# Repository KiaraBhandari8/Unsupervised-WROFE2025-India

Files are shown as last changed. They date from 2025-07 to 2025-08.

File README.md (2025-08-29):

# Unsupervised-WROFE2025-India
This is a repository for our WRO Future Engineers 2025 documentation. 

## Table of Contents
- [Unsupervised-WROFE2025-India](#unsupervised-wrofe2025-india)
  - [Table of Contents](#table-of-contents)
  - [Team](#team)
  - [About the challenge](#about-the-challenge)
  - [List of Components](#list-of-components)
  - [Robot Pictures](#robot-pictures)
  - [Design, Build, Code and Evaluate Process](#design-build-code-and-evaluate-process)
    - [Design](#design)
    - [Mobility Management](#mobility-management)
      - [Powertrain](#powertrain)
        - [Drivetrain](#drivetrain)
        - [Motor](#motor)
        - [Motor Driver](#motor-driver)
    - [Build](#build)
      - [Chassis](#chassis)
      - [Steering Mechanism](#steering-mechanism)
      - [Drive Mechanism](#drive-mechanism)
    - [Sensors and Perception](#sensors-and-perception)
      - [LiDAR – YDLIDAR T-mini Plus](#lidar--ydlidar-t-mini-plus)
      - [Camera – Raspberry Pi Camera Module 3 (Wide)](#camera--raspberry-pi-camera-module-3-wide)
    - [Power and sense management](#power-and-sense-management)
        - [DC Buck Converter:](#dc-buck-converter)
      - [Lithium Ion batteries:](#lithium-ion-batteries)
      - [Open Round Algorithm](#open-round-algorithm)
      - [Obstacle Round Algorithm](#obstacle-round-algorithm)
    - [Final Evaluation \& Scores](#final-evaluation--scores)
- [🚀 Robot Construction Guide](#-robot-construction-guide)
  - [🖨️ Step 0: Print the 3D Parts](#️-step-0-print-the-3d-parts)
    - [1. Prepare the microSD Card](#1-prepare-the-microsd-card)
    - [2. First Boot](#2-first-boot)
    - [3. Enable Required Interfaces](#3-enable-required-interfaces)
  - [Running the Code](#running-the-code)

## Team

<table style="width:100%; border: 1px solid black; border-collapse: collapse;">
  <thead>
    <tr>
      <th style="border: 1px solid black; padding: 8px;">Name</th>
      <th style="border: 1px solid black; padding: 8px;">Profile</th>
      <th style="border: 1px solid black; padding: 8px;">Role</th>
      <th style="border: 1px solid black; padding: 8px;">Contribution</th>
    </tr>
  </thead>
  <tbody>
    <tr>
      <td style="border: 1px solid black; padding: 8px;">1. Arnav Ramtake</td>
      <td style="border: 1px solid black; padding: 8px;">3rd year undergrad @ IIT Bombay</td>
      <td style="border: 1px solid black; padding: 8px;">Team Member</td>
      <td style="border: 1px solid black; padding: 8px;">Project development & Testing</td>
    </tr>
    <tr>
      <td style="border: 1px solid black; padding: 8px;">2. Kiara Bhandari</td>
      <td style="border: 1px solid black; padding: 8px;">Grade 9 @ Oberoi International School</td>
      <td style="border: 1px solid black; padding: 8px;">Team Member</td>
      <td style="border: 1px solid black; padding: 8px;">Project development & Testing</td>
    </tr>
    <tr>
      <td style="border: 1px solid black; padding: 8px;">3. Shubh Gupta</td>
      <td style="border: 1px solid black; padding: 8px;">Grade 9 @ Chatrabhuj Narsee School</td>
      <td style="border: 1px solid black; padding: 8px;">Team Member</td>
      <td style="border: 1px solid black; padding: 8px;">Project development & Testing</td>
    </tr>
    <tr>
      <td style="border: 1px solid black; padding: 8px;">4. Vinay Ummadi</td>
      <td style="border: 1px solid black; padding: 8px;">Mentor @ MakerWorks Lab</td>
      <td style="border: 1px solid black; padding: 8px;">Team Mentor</td>
      <td style="border: 1px solid black; padding: 8px;">Provided guidance and support</td>
    </tr>
  </tbody>
</table>

Team picture:

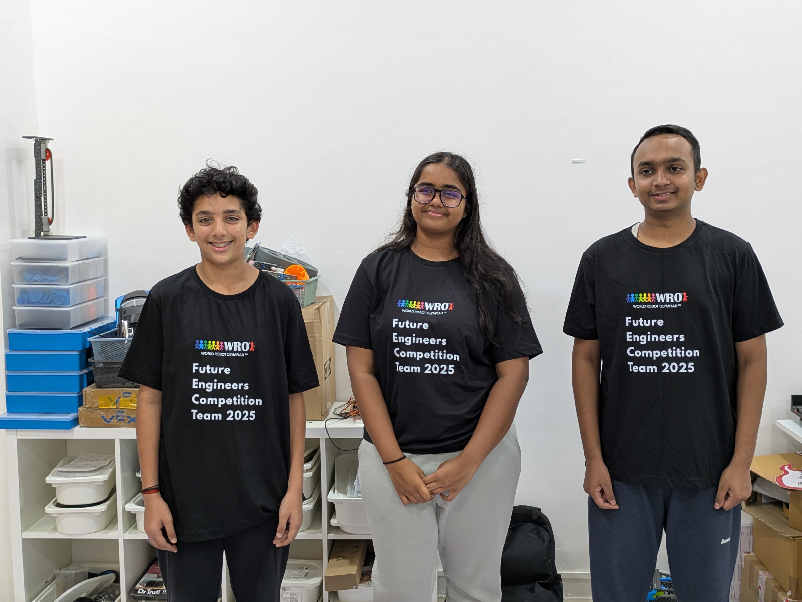
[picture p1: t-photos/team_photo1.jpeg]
Team Picture


## About the challenge
The World Robot Olympiad (WRO) is an international robotics competition that encourages students to develop problem-solving, programming, and engineering skills.
The Future Engineers category is designed for students aged 14–22 years and focuses on autonomous driving. The challenge simulates real-world traffic conditions and requires teams to design and program a fully autonomous robot car.

The challenge requires students to construct an autonomous robot which will undergo 2 rounds. First, an open round challenge where the robot would need to complete 3 rounds around the arena within the time limit of 3 minutes (180 seconds). The second round, which is the obstacle round consists of navigating through red and green pillars, where the robot would move from the left of the green pillar and from right of the red pillar. The robot should once again, not exceed a time limit of 3 minutes.

## List of Components
<table border="1">
  <thead>
    <tr>
      <th>Component Name with Link</th>
      <th>Quantity</th>
      <th>Price</th>
    </tr>
  </thead>
  <tbody>
    <tr>
    <td><a href="https://robu.in/product/n20-6v-600-rpm-micro-metal-gear-motor/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">N20 DC Gear Motor</a></td>
      <td>1</td>
      <td>₹239</td>
    </tr>
    <tr>
    <td><a href="https://robu.in/product/raspberry-pi-5-model-8gb/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">Raspberry Pi 5 (Cooling Fan + SD Card)</a></td>
      <td>1</td>
      <td>₹8,291</td>
    </tr>
      <tr>
    <td><a href="https://robu.in/product/raspberry-pi-camera-module-3-wide/"> Pi Camera 3 Wide Angle</a></td>
      <td>1</td>
      <td>₹500</td>
    </tr>
      <tr>
    <td><a href="https://share.google/GQIqzE7hObWl2JtNW">TB6612FNG Motor Driver</a></td>
      <td>1</td>
      <td>₹161</td>
    </tr>
      <tr>
    <td><a href="https://share.google/SYj7opQ4mhcO487lK">MG996R Servo Motor</a></td>
      <td>1</td>
      <td>₹347</td>
    </tr>
      <tr>
    <td><a href="https://robu.in/product/16-channel-12-bit-pwmservo-driver-i2c-interface-pca9685-arduino-raspberry-pi/">PCA9685 Servo Driver</a></td>
      <td>1</td>
      <td>₹223</td>
    </tr>
      <tr>
    <td><a href="https://share.google/BG01lgffrP5yxi8mK">N20 Wheels</a></td>
      <td>4</td>
      <td>₹140</td>
    </tr>
      <tr>
    <td><a href="https://share.google/xb8SxxgjGmudeReLK">LM2596S Voltage Regulator</a></td>
      <td>1</td>
      <td>₹41</td>
    </tr>
      <tr>
    <td><a href="https://robu.in/product/ydlidar-t-mini-plus-lidar-sensor/">YD LiDAR T-mini plus</a></td>
      <td>1</td>
      <td>₹9,595</td>
    </tr>
      <tr>
    <td><a href="https://www.amazon.in/Ambrane-Charging-Powerbank-Emergency-30/dp/B0D351GHY7?th=1">Power Bank</a></td>
      <td>1</td>
      <td>₹1,699</td>
    </tr>
      <tr>
    <td><a href="https://makerbazar.in/products/18650-3-7v-lithium-ion-rechargeable-cell-good-quality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">18650 Battery</a></td>
      <td>2</td>
      <td>₹35</td>
    </tr>
      <tr>
    <td><a href="https://share.google/fq9tZREMioah3AI9Q">Push Button Switch</a></td>
      <td>1</td>
      <td>₹46</td>
    </tr>
      <tr>
    <td><a href="https://robu.in/product/pct-spl-62-0-08-2-5mm-62-pole-wire-connector-terminal-block-with-spring-lock-lever-for-cable-connection/">Wire Connectors</a></td>
      <td>1</td>
      <td>₹58</td>
    </tr>
      </tr>
      <tr>
    <td><a href="https://www.mathaelectronics.com/product/4-pole-2-way-dpdt-12pin-on-off-switch/">4 Pole 2 Way DPDT 12 pin ON/OFF Switch</a></td>
      <td>1</td>
      <td>₹500</td>
    </tr>
    <tr>
    <td><a href="[https://share.google/fq9tZREMioah3AI9Q](https://www.amazon.in/dp/B0D9VWCX66?ref=ppx_yo2ov_dt_b_fed_asin_title)">RC Car Rear Differential</a></td>
      <td>1</td>
      <td>₹1,275</td>
    </tr>

  </tbody>
</table>

## Robot Pictures
<table border="1">
  <thead>
    <tr>
      <th>Top</th>
      <th>Bottom</th>
    </tr>
  </thead>
  <tr>
    <td>
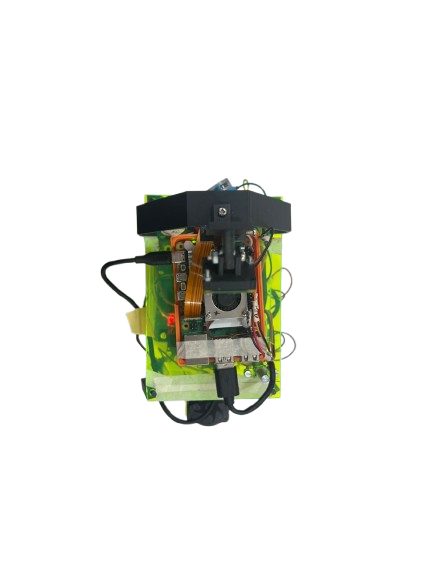
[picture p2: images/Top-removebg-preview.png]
Robot_Top
  </td>
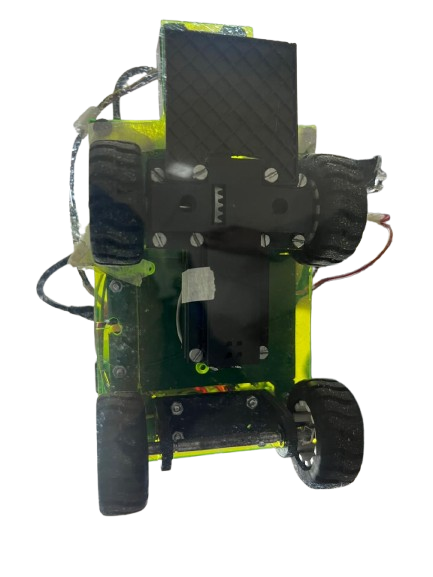
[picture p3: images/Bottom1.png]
Robot_Bottom
    <td></td>
  </tr>
  <thead>
    <tr>
      <th>Front</th>
      <th>Back</th>
    </tr>
  </thead>
  <tr>
    <td>
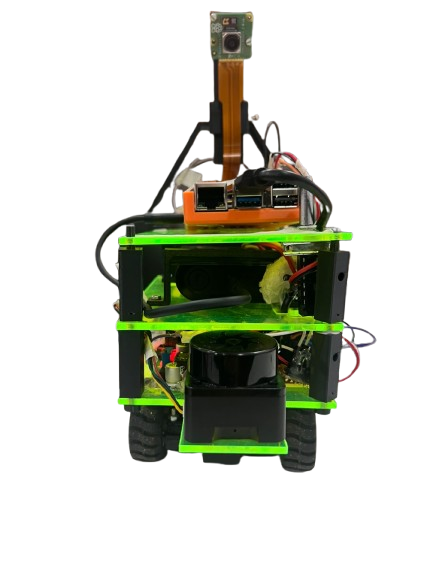
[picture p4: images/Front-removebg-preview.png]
Robot_Front
  </td>
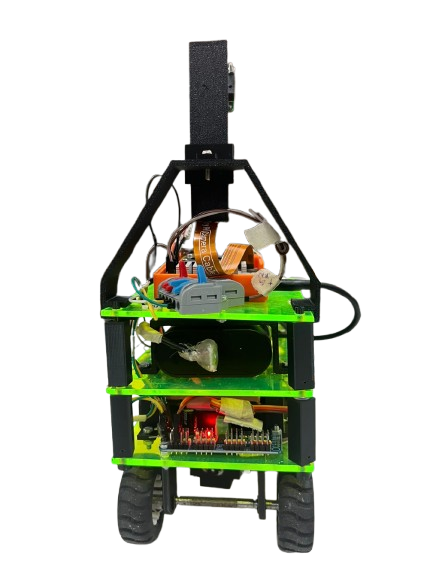
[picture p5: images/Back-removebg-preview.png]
Robot_Back
    <td></td>
  </tr>
   <thead>
    <tr>
      <th>Left</th>
      <th>Right</th>
    </tr>
  </thead>
  <tr>
    <td>
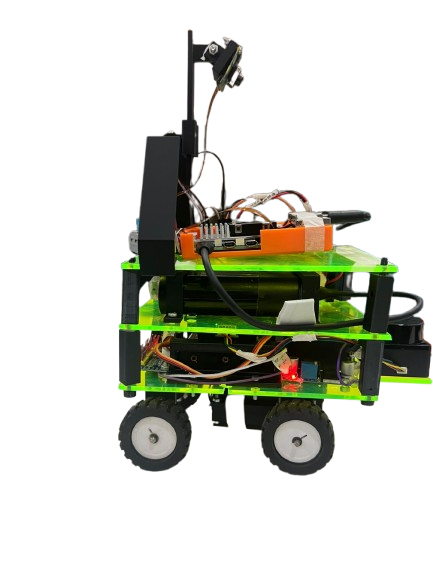
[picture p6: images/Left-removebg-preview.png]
Robot_Left
  </td>
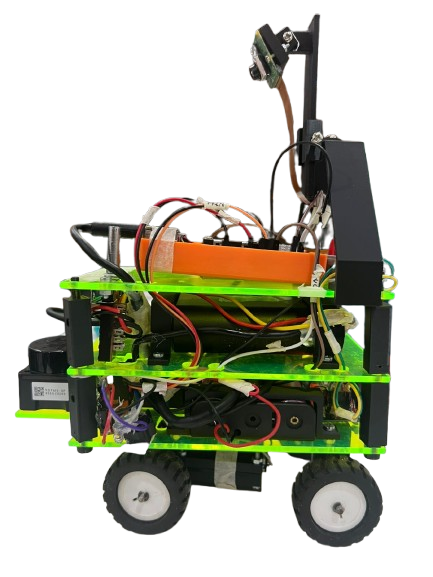
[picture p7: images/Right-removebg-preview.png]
Robot_Right
    <td></td>
  </tr>
</table>

### Design Process
We started understading the given constraints and physical requirements of the robot and then designed the robot to meet these requirements. The design process included:
- **Understanding the Problem Statement**: We analyzed the requirements and constraints of the WRO Future Engineers 2025 competition.
- **Conceptualizing the Robot**: We brainstormed ideas for the robot's design, focusing on its chassis, steering mechanism, drive mechanism, sensors, and power management.
- **Creating Design Diagrams**: We created detailed design diagrams to visualize the robot's structure and components. These diagrams included:
  - Chassis design
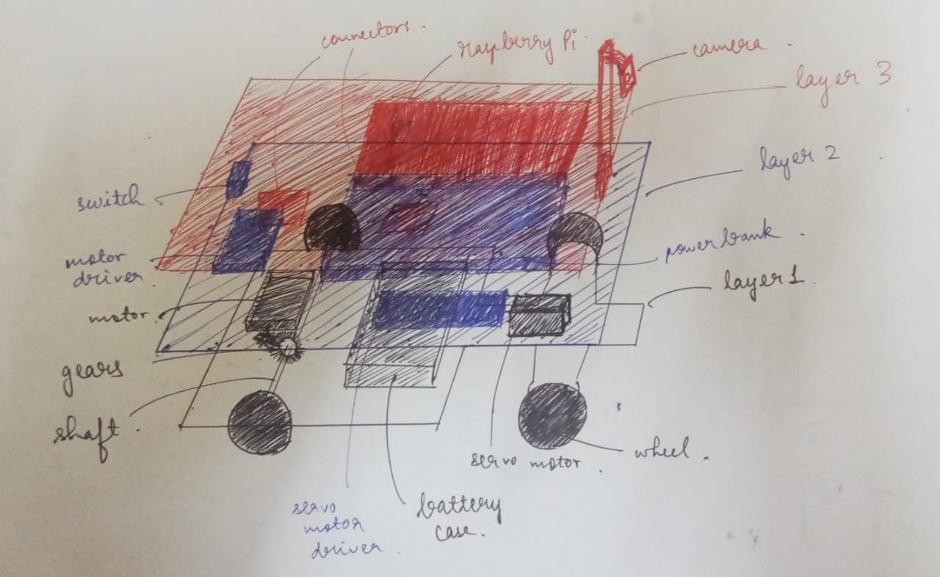
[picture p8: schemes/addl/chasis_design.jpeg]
Chasis Design Drawing
  

  - Steering mechanism design
  
  - Drive mechanism design      

### Mobility Management

The robot's mobility is managed by a combination of compoenents, icluding the powertrain, sterring system and chassis. These elements work together to ensure the robot's smooth and efficient movement. 

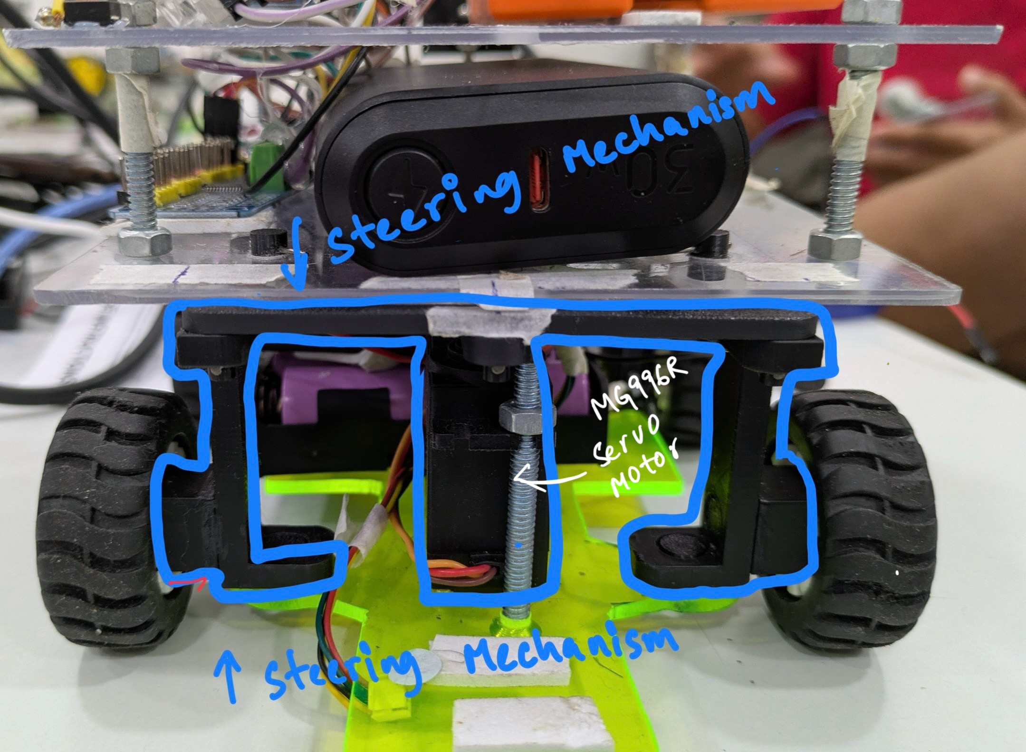
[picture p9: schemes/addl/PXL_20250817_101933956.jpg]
Drive Mechanism


#### Powertrain 

##### Drivetrain 
To minimize friction and therby reduce speed loss, driving axle was made from an steel rod. We connected the orot to the riving axle using a custom 3-D printed adapter. The driing axle is equipped with differential gears, which allow the robot to turn smoothly. For traction we used N20 wheels. 

Potential Improvements:

- Upgrade to higher-quality differential gear set for enhanced efficiency and smoother cornering. 
- Experiment with lighter alloys and hollow rods to balance strength with reduced weight. 
- Replace the 3D printed adapter with a kachined metal one for greater durability and precision. 

##### Motor

N20 DC Gear motor:
<table border="1">
  <thead>
    <tr>
      <th style="width:300;">Component Image</th>
      <th style="width:200;">Specifications:</th>
    </tr>
  </thead>
  <tbody>
      <tr>
        <td>N20 dc Gear motor</td>
        <td>
          1. Name: N20 dc Gear Motor
          <br>
          <br>
          2. Speed Range:  ~ 30 RPm to ~ 2000 RPM
          <br>
          <br>
          3. High torque at low RPM due to gearbox
        </td>
      </tr>
  </tbody>
</table>

Following an evaluation of different motors, we settles on the **N20-6V-600 Rpm Micro Metal Gear Motor**. THis motor was selected for its lightweight and compact design, which stands out among others with comparable output. We secured the motor to the chassis using a custom 3-D printed holder. 

Where to buy the motor: (insert link)

To connect the motor's axle to the chassis, we created a custom 3D - printed adapter. 

(insert 3D model)

Potential Improvements:
- Consider upgrading to a higher-torque or lower-RPM variant of the N20 motor for improved control and load handling.
- Replace the custom 3D-printed adapter with a machined metal connector to enhance strength and long-term reliability.
- Implement a sturdier motor mount or holder to minimize vibrations and ensure better alignment with the axle.

Drive Mechanism

##### Motor Driver 

To control the speed of the drive motor, we utilized the SparkFun Dual TB6612FNG motor driver. 

<table border="1">
  <thead>
    <tr>
      <th style="width:300;">Component Image</th>
      <th style="width:200;">Specifications:</th>
    </tr>
  </thead>
  <tbody>
      <tr>
        <td>TB6612FNG Motor driver</td>
        <td>
          1. Name: TB6612FNG
          <br>
          <br>
          2. Motor Voltage (VM): 4.5–13.5 V
          <br>
          <br>
          3. Logic Voltage (VCC): 2.7–5.5 V
          <br>
          <br>
          4. Output Current: 1.2 A continuous, 3.2 A peak per channel
          <br>
          <br>
          5. Control Pins: Direction, PWM speed, Standby
        </td>
      </tr>
  </tbody>
</table>

Where to buy the motor drive: https://www.sparkfun.com/sparkfun-motor-driver-dual-tb6612fng-with-headers.html

Potential Improvements:
- Replace the motor driver with a custom PCB to reduce weight and improve space utiliation 
- Add active cooling or heating sinks for enhanced thermal performance during extended use.
- Explore higher-current motor drivers to accomodate potential motor upgrades. 
- Implement a more robust power manangement system to ensure reliable operation. 

### Build

#### Chassis
The robot chasis is mainly designed from acrylic and 3d desgined parts. Robot consists of multiple layers to accommodate various components. Every structural component was fastened firmly with bolts and nuts to ensure durability and rigidity required for testing. For enhanced performance, the bottom acrylic sheet was carefully trimmed along the wheel areas, allowing for free wheel rotation and better maneuverability. Instead of expanding the robot's dimensyions in horizantally that would impact maneuverability, we opted for a three-layer vertical configuration. Not only did this choice in design improve space efficiency, but it also boosted the robot's performance by allowing better integration of its mechanical and electronic components in a compact footprint. The robot dimensions are 14cm(width) x 19cm(length) x 20cm(height). 

#### Steering Mechanism
The robot employs a distinct and novel steering mechanism designed to achieve efficient and reliable maneuvering using a single servo motor. An MG996R high-torque servo motor is directly coupled to the steering linkage, allowing both front wheels to turn at the same angle simultaneously. The forward wheels are free to rotate independently and are supported by a differential gear system, which ensures that each wheel can rotate at the appropriate speed when the robot takes a turn. This is essential because the outer wheel must travel a greater distance than the inner wheel during cornering, and the differential allows this motion without skidding or energy loss. By combining the servo-driven steering system with differential gears, the robot achieves precise steering control, mechanical efficiency, and smooth navigation across both straight paths and turns.
MG996r Servo Motor:
<table border="1">
  <thead>
    <tr>
      <th style="width:300;">Component Image</th>
      <th style="width:200;">Details</th>
    </tr>
  </thead>
  <tbody>
      <tr>
        <td>MG996r servo motor</td>
        <td>
          1. MG996r Servo motor
          <br>
          <br>
          2. Digital servo: Pulse width modulation controlled(PWM)
        </td>
      </tr>
  </tbody>
</table>

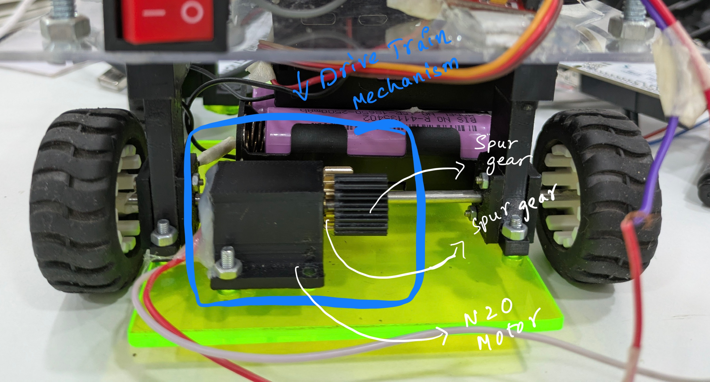
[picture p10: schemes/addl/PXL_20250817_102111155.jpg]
Steering Mechanism


#### Drive Mechanism
An N20 DC gear motor powers the driving mechanism of the robot,transferring motion to the rear axle of the wheels via a gear system.The N20 motor is a small and light device (around 12 mm in diameter and weighing 10–12 g), frequently utilized in miniature robotics and DIY projects. It comes in 3 V, 6 V, and 12 V options, featuring gear ratios from 10:1 to 1000:1, allowing for a balance of speed and torque—lower ratios yield increased speed, while higher ratios offer enhanced torque. Featuring a 3 mm D-shaped output shaft and a robust metal gearbox, the N20 motor provides easy mounting affordability, and versatility, making it ideal for applications like line-following robots,remote-controlled vehicles, and small actuation systems.

N20 DC Gear motor:
<table border="1">
  <thead>
    <tr>
      <th style="width:300;">Component Image</th>
      <th style="width:200;">Details</th>
    </tr>
  </thead>
  <tbody>
      <tr>
        <td>N20 dc Gear motor</td>
        <td>
          1. N20 dc Gear Motor
          <br>
          <br>
          2. Speed range (depends on gear ratio): from ~30 RPM (high torque) to ~1000 RPM (low torque)
          <br>
          <br>
          3. High torque at low RPM due to gearbox
        </td>
      </tr>
  </tbody>
</table>

Drive Mechanism

### Sensors and Perception

#### LiDAR – YDLIDAR T-mini Plus
<table border="1">
  <thead>
    <tr>
      <th style="width:300;">Component Image</th>
      <th style="width:200;">Details</th>
    </tr>
  </thead>
  <tbody>
      <tr>
        <td>YD Lidar T-mini plus
        <td>
          • Model: YDLIDAR T-mini Plus  
          <br><br>
          • 360° scanning capability for complete environmental awareness  
          <br><br>
          • Maximum range: up to 12 meters  
          <br><br>
          • Provides high-frequency distance and angle data for mapping and navigation
        </td>
      </tr>
  </tbody>
</table>

The LiDAR sensor operates on the principle of **time-of-flight measurement**, emitting rapid laser pulses and calculating the return time after striking objects. This provides precise range and angular data, enabling the robot to construct accurate real-time maps of its surroundings. Its wide scanning field, high accuracy, and fast update rate make it essential for **obstacle detection, Simultaneous Localization and Mapping (SLAM), and terrain mapping**. With LiDAR, the robot can not only avoid obstacles but also refine its spatial understanding continuously, ensuring smooth navigation even in dynamic or unfamiliar environments.

Potential Improvements:
+ Use RANSAC line fitting or clustering to detect walls and obstacles more reliably
+ Apply filtering (median, moving average, outlier rejection, low-pass on derivative) for smoother control inputs
+ Add gain scheduling or adaptive PID to adjust steering dynamically with speed and environment
+ Try predictive controllers like Pure Pursuit, Stanley, or MPC for smoother navigation
+ Fuse LiDAR with IMU/encoders for better localization and drift correction
+ Use dynamic window or VFH (Vector Field Histogram) for local obstacle avoidance
+ Apply SLAM or map-based localization for improved path planning in complex environments
+ Add trajectory prediction to handle moving obstacles effectively

#### Camera – Raspberry Pi Camera Module 3 (Wide)
<table border="1">
  <thead>
    <tr>
      <th style="width:300;">Component Image</th>
      <th style="width:200;">Details</th>
    </tr>
  </thead>
  <tbody>
<tr>
        <td>Raspberry Pi camera module 3 wide angle
        </td>
        <td>
          • 12 MP Sony IMX708 sensor with HDR support  
          <br><br>
          • 120° ultra-wide diagonal field of view (≈102° horizontal, 67° vertical)  
          <br><br>
          • Phase-detect autofocus for sharp imaging  
          <br><br>
          • 1080p video at up to 50 fps for real-time processing
        </td>
      </tr>
  </tbody>
</table>

The Raspberry Pi Camera Module 3 (Wide) was chosen due to its ability to capture a broad field of view, critical for detecting obstacles, monitoring lanes, and ensuring spatial awareness with fewer blind spots. Its **high-resolution sensor and HDR capability** deliver clear images across varying light conditions, while the autofocus ensures reliable detection of both nearby and distant objects. The **high frame rate (50 fps)** ensures smooth real-time video streaming, which is vital for **vision-based navigation, SLAM, and obstacle recognition**. This makes it an optimal perception sensor for the robot’s autonomous operation.

Potential Improvements:

+ Upgrade to a camera with higher resolution for better object detection and tracking.
+ Test alternative lighting solutions to improve visibility in various conditions.
+ Implement advanced image processing algorithms to enhance detection accuracy.
+ Use color correction algorithms: Apply color correction algorithms to compensate for any variations in lighting conditions. These algorithms can adjust the color values of the captured image to match a reference color space, making the colors more consistent and easier to calibrate.
+ Provide user-adjustable parameters: Allow users to manually adjust color thresholds or ranges to fine-tune the color detection. This can be done through a user interface or by providing configuration files that can be modified.
+ Implement real-time feedback: Display the detected colors in real-time to the user, along with the calibrated values. This allows users to visually verify the accuracy of the color detection and make adjustments if necessary.

### Power and sense management

##### DC Buck Converter:
<table border="1">
  <thead>
    <tr>
      <th style="width:300;">Component Image</th>
      <th style="width:200;">Details</th>
    </tr>
  </thead>
  <tbody>
      <tr>
        <td>LM2596S Voltage Regulator</td>
        <td>
          1. DC buck converter  
          <br>
          <br>
          2. A buck converter or step-down converter is a DC-to-DC converter which decreases voltage, while increasing current, from its input (supply) to its output (load)
          <br>
          <br>
          3. DC-DC converter
        </td>
      </tr>
  </tbody>
</table>

The robot is powered by a 3-cell 18650 battery pack (~11.1 V nominal), which acts as the main source of energy. Since the subsystems operate at different voltages, a two-rail power setup is used:

+ Direct 11.1 V rail – drives components that can operate directly from the pack
+ 3.3 V regulated rail – derived using an LM2596 buck DC-DC converter

The LM2596 was chosen because it provides 80–90% efficiency, avoiding the excessive heat losses of linear regulators. It also ensures:

+ Stable 3.3 V output across the pack’s 9–12.6 V range
+ Reliable operation of sensors, logic, and microcontrollers
+ Adequate current headroom for the control electronics
+ Simplified power management and protection of sensitive devices

#### Lithium Ion batteries:
 <table border="1">
  <thead>
    <tr>
      <th style="width:300;">Component Image</th>
      <th style="width:200;">Details</th>
    </tr>
  </thead>
  <tbody>
 <tr>
        <td>18650 lithium ion batteries
        </td>
        <td>
          1. 18650 Lithium Ion batteries (11.1 V) 
          <br>
          <br>
          2. High energy density and capacity, leading to longer usage times and more power in a small package. 
        </td>
      </tr>
  </tbody>
</table>

The robot is powered by a 3-cell 18650 non-rechargeable battery pack (11.1 V nominal), selected to balance reliability, compactness, and sufficient energy supply for autonomous operation.

+ Stable voltage output – consistently provides ~11.1 V (9–12.6 V range) suitable for motors, sensors, and control boards
+ Non-rechargeable chemistry – eliminates risks of recharge-related degradation, swelling, or maintenance, ensuring dependable short- to medium-term use
+ Motor compatibility – higher voltage level supports motor drivers more effectively than AA or 9 V alternatives
+ Extended runtime – high energy density of 18650 cells delivers longer operation before replacement compared to conventional disposable batteries
+ Compact and lightweight – cylindrical form factor makes the pack easy to integrate without adding unnecessary bulk
+ Consistent discharge curve – maintains steady performance over usage cycle, preventing voltage drops that could affect control electronics

### 18650 Battery holder
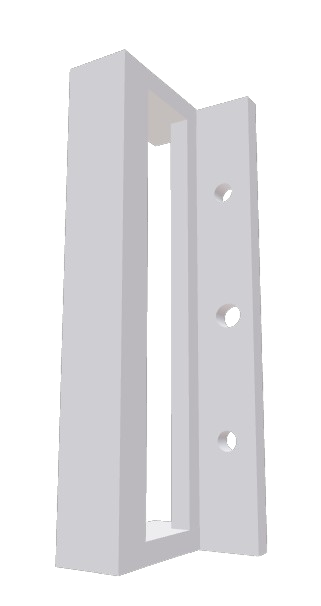
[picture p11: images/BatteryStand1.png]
Battery Holder


+ Compact Form Factor – The slim rectangular frame securely houses the 3-cell 18650 pack while minimizing wasted volume, making it well-suited for robots with limited internal space.
+ Structural Stability – The rigid walls and elongated side frame provide strong mechanical support, preventing cell movement or vibration during operation.
+ Mounting Flexibility – Pre-drilled holes allow easy attachment to the robot chassis, reducing the need for additional brackets or adhesives.
+ Weight Optimization – Open frame design reduces unnecessary material use, keeping the holder lightweight without compromising durability.
+ Thermal Management – The open sides promote airflow around the batteries, preventing heat buildup and improving safety during high-current discharge.
+ Maintenance-Friendly – The accessible frame allows straightforward battery replacement, inspection, or wiring adjustments.
+ Secure Alignment – Ensures the 18650 cells remain aligned in series/parallel configuration, reducing electrical contact resistance and improving power reliability.

#### Power Bank holder:
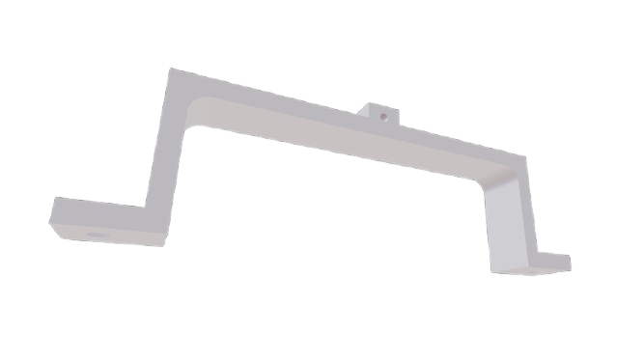
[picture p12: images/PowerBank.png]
Power Bank Holder


+ Minimalistic frame reduces material use, keeping it lightweight yet strong
+ Raised side arms secure the power bank and prevent shifting during operation
+ Central mounting hole allows easy attachment to the chassis
+ Open design ensures quick access for wiring and charging without removal
+ Provides airflow around the power bank for passive cooling
+ Stable and practical mounting without adding bulk to the robot

#### Potential Improvements:
+ Use rubber padding or cushioning to reduce shock and protect the power bank from mechanical stress.
+ Design for tool-less removal so the power bank can be swapped quickly.
+ Include cable management features (clips or slots) to keep wires tidy and strain-free
+ Add universal sizing adjustability to fit different power bank models if needed.
+ Optimize the weight distribution so the holder doesn’t affect the robots performance

## Open Round Algorithm
### 1) Initialization
+ Robot initializes LiDAR and motion subsystems.
+ A 5-second pause allows hardware to stabilize.
+ PID controller parameters (Kp, Ki, Kd) are set depending on clockwise/anticlockwise wall-following mode.

### 2) LiDAR Data Acquisition
+ The LidarScanner continuously collects angle–distance pairs (-180° to +180°).
+ Distances are filtered to valid ranges, converted to millimeters, and stored in a dictionary.

### 3) Turn Detection
+ Front LiDAR readings (±10° sector) are averaged separately for left and right.
+ If both fall within a threshold range (1500–2000 mm), the system flags a turn condition.
+ Turn events are counted, but with a cooldown (≥2.5 s) to avoid multiple detections for the same turn.

### 4) Wall Distance Processing
+ Right wall sector: 30° to 90°.
+ Left wall sector: -90° to -30°.
+ Front sector: -5° to +5° (safety check).
+ Distances in each sector are averaged to estimate proximity to arena walls.

### 5) Error Calculation:
The four conditions include:
+ If both walls are visible: error = (right distance – left distance) → keeps robot centered.
+ If only one wall is visible: error = (wall distance – target distance) → maintains fixed offset.
+ If no walls detected: error = 0 → hold course.
+ If front obstacle is closer than safety threshold (e.g., <300 mm): error = 9999 (forces emergency stop).

### 6) PID Control
+ The error is fed into a PID controller to smooth steering response.
+ PID output adjusts servo angle around a center position (≈95°).
+ Output is clamped to ±20° for safe steering limits.

### 7) Motion Control
+ If no obstacle: robot moves forward at constant speed (0.6).
+ Servo adjusts steering continuously to minimize PID error.
+ If obstacle detected: robot stops, pauses, and waits before continuing.

### 8) Termination Condition
+ After max_turn_count = 12 turns, the robot stops permanently (end of round).

## Step by step breakdown of functions (Open Round):

### 1) read_lidar_data(lidar):
``` bash
def read_lidar_data(lidar):
    """
    Reads distance values from the LiDAR sensor between -90° and +90°.
    Splits the scan into LEFT, RIGHT, and FORWARD zones.
    Returns the average distance in each zone to minimize noise.
    """
    scan = lidar.get_scan()   # assumes lidar API gives [(angle, distance), ...]

    # Split the scan into zones
    left_distances = [d for (a, d) in scan if -90 <= a < -30]
    right_distances = [d for (a, d) in scan if 30 <= a <= 90]
    forward_distances = [d for (a, d) in scan if -15 <= a <= 15]

    # Compute average values (if no points, default to 0)
    left_avg = sum(left_distances)/len(left_distances) if left_distances else 0
    right_avg = sum(right_distances)/len(right_distances) if right_distances else 0
    forward_avg = sum(forward_distances)/len(forward_distances) if forward_distances else 0
    
    return left_avg, right_avg, forward_avg

```
### Explanation:
+ The LiDAR constantly scans in a 180° range around the front of the robot.
+ Data is divided into zones:
  + Left zone: -90° to -30°
  + Right zone: +30° to +90°
  + Forward zone: -15° to +15°
+ By averaging readings, sudden spikes (noise) are reduced.
+ The robot then knows how far it is from left wall, right wall, and any object in front.

### compute_wall_error:
``` bash
def compute_wall_error(left, right):
    """
    Calculates the lateral error between left and right distances.
    Positive error → robot is closer to the RIGHT wall, so it must steer LEFT.
    Negative error → robot is closer to the LEFT wall, so it must steer RIGHT.
    """
    return left - right
```
### Explanation:
+ This function ensures the robot stays centered in the arena.
+ If left > right → robot is drifting towards the right wall → needs to turn left.
+ If right > left → robot is drifting towards the left wall → needs to turn right.
+ The error value is passed into the PID controller for smooth correction.

### pid_controller:
```bash
integral = 0
prev_error = 0

def pid_controller(error, Kp=1.2, Ki=0.01, Kd=0.5, dt=0.1):
    """
    PID controller that takes in an error value and outputs a steering correction angle.
    - Proportional (P): reacts immediately to the error.
    - Integral (I): fixes long-term drift or bias.
    - Derivative (D): anticipates changes and prevents overshoot.
    dt: time difference between control cycles.
    """
    global integral, prev_error
    
    integral += error * dt
    derivative = (error - prev_error) / dt
    output = (Kp * error) + (Ki * integral) + (Kd * derivative)
    
    prev_error = error
    return output
```
### Explanation:
+ This is the core control function.
+ Works just like an autopilot system.
+ P (Proportional) – responds strongly to the current error.
+ I (Integral) – accumulates small errors over time (helps correct drift).
+ D (Derivative) – predicts future error change to avoid oscillations.
+ Outputs a steering correction angle for the servo.

### adjust_steering(servo, angle):
```bash
def adjust_steering(servo, angle):
    """
    Adjusts the MG996R steering servo based on PID output.
    Clamps the steering angle to [-45°, +45°] to prevent mechanical strain.
    """
    max_angle = 45
    angle = max(min(angle, max_angle), -max_angle)  # clamp
    
    servo.write(angle)  # assumes servo driver library
```

### Explanation:
+ Converts PID output into servo rotation.
+ Prevents excessive turning (>45°) which could damage servo or robot frame.
+ Responsible for real-time navigation corrections.

### control_motors(driver, speed):
``` bash
def control_motors(driver, speed):
    """
    Controls the TB6612FNG motor driver.
    Sends equal PWM speed signals to left & right motors for forward motion.
    Speed range is 0–255.
    """
    driver.set_motor_speed(speed, speed)  # equal speed for both wheels
```

### Explanation:
+ Keeps robot moving forward with a constant speed.
+ Uses PWM signals to the TB6612FNG driver.
+ If needed, can be extended to allow different left/right speeds for sharper turns.

### check_termination(forward_distance, lap_count, max_laps):
```bash
def check_termination(forward_distance, lap_count, max_laps=3):
    """
    Checks if the run should terminate.
    Conditions:
    - If forward distance < threshold → obstacle or wall detected.
    - If lap_count >= max_laps → required laps completed.
    Returns True if termination condition is met.
    """
    if forward_distance < 20:  # cm threshold
        return True
    if lap_count >= max_laps:
        return True
    return False
```

### Explanation:
+ Ensures robot doesn’t run forever.
+ Two termination conditions:
  + Obstacle detected in front (arena end or unexpected block).
  + All laps completed (challenge success).
+ Returns True → robot stops.

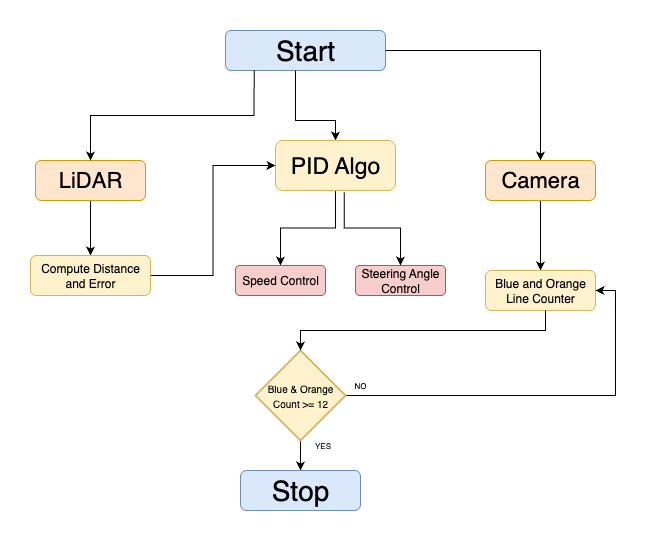
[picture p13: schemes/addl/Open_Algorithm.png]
Open Round Algorithm


## Obstacle Round Algorithm
The obstacle round uses a **hybrid sensing and control system** where LiDAR and camera inputs are fused together to identify obstacles, calculate errors, and generate steering corrections. The system is structured into multiple layers: sensing, perception, control, and actuation.

### 1) LiDAR-Based Obstacle Detection
+ **Sensor**: YDLidar T-mini Plus provides a **270° scan**, but only **-90° to +90° relative to robot’s forward axis** is considered.  
+ **Preprocessing**:  
  - Filters raw data for outliers (values beyond sensor max range).  
  - Segments detected points into clusters representing potential obstacles.  
+ **Pillar Identification**:  
  - Uses expected pillar spacing to detect red/green pillar positions.  
  - Calculates **lateral offset error** = difference between current robot position and target trajectory (pass left of green, right of red).  
+ **Use Case**:  
  - Provides **fail-safe navigation** when camera detection fails (e.g., poor lighting).  
  - Supplies continuous lateral distance measurement to support stable alignment.

### 2) Camera-Based Color Detection Algorithm
The camera system adds semantic information (pillar color), which LiDAR alone cannot provide.

+ **Frame Acquisition & Preprocessing**  
  - Captures frames using **PiCamera2** at 2304×1296.  
  - Resized and blurred to reduce noise before color segmentation.  
  - Conversion **BGR → HSV** for robust color thresholding under variable lighting.  

+ **Color Segmentation**  
  - Predefined HSV thresholds for **red** and **green**.  
  - Binary masks created for each color channel.  
  - Morphological operations (erode, dilate) applied to reduce noise.  

+ **Region of Interest (ROI)**  
  - Inner ROI = normal detection zone.  
  - Outer ROI = activated when LiDAR detects an obstacle cluster ahead.  
  - Dual-ROI design reduces false positives from irrelevant background features.  

+ **Contour Detection & Validation**  
  - Extracts contours from binary masks.  
  - Rejects contours smaller than **MIN_CONTOUR_AREA = 1500**.  
  - Selects the largest contour per frame as the obstacle candidate.  
  - Assigns detection labels:  
    - `"red_obstacle"` → valid red pillar.  
    - `"green_obstacle"` → valid green pillar.  
    - `"obstacle"` → unidentified object.  
    - `"none"` → no valid obstacle.  

+ **Depth Sensitivity Factor**  
  - Implements **DEPTH_IMPORTANCE_FACTOR = 1.35**.  
  - Vertical pixel location of contour centroid (closer to bottom = nearer).  
  - Error signal scaled accordingly:  
    - Far object → low correction.  
    - Near object → stronger correction.  

+ **Steering Logic (Camera)**  
  - Red pillar → steer left with correction `steering = KP_STEERING × error × depth_factor`.  
  - Green pillar → steer right with same correction logic.  
  - Maintains flexibility for real-time corrections based on object position.  

+ **Fallback Mechanisms**  
  - If **no obstacle detected** → black region between floor lines is used for centering.  
  - If **frame underexposed** → assumes corner → performs sharp left turn (≈ -45°).  
  - Prevents robot from stalling during sensor failure.  

+ **Debugging Visual Overlays**  
  - Draws bounding boxes, centroids, ROI zones, and target lines.  
  - Displays numerical feedback (depth factor, correction angle).  
  - Useful for tuning HSV thresholds and ROI positions in real-time.  

### 3) Sensor Fusion & PID Steering Control
+ **Error Calculation**  
  - `LiDAR_error` = difference between distances to left/right wall.  
  - `Camera_error` = lateral offset of detected pillar.  
  - Fusion weights:  
    - **LiDAR dominant** if no valid pillar detected.  
    - **Camera dominant** if pillar is confirmed in ROI.  

+ **PID Controller**  
  - Input = combined error (LiDAR + Camera).  
  - **Kp (Proportional)** → quick correction response.  
  - **Ki (Integral)** → compensates for slow drift across laps.  
  - **Kd (Derivative)** → damps oscillations during sharp turns.  
  - Tuning values are selected through iterative testing for balance between stability and responsiveness.  

+ **Output**  
  - PID output mapped to **MG996R servo angle**.  
  - Motor PWM adjusted to maintain forward speed while avoiding jerks during corrections.  

### 4) Decision Flow & Execution
+ Final control decision is based on **sensor fusion state**:  
  - `"red_obstacle"` → steer left of pillar.  
  - `"green_obstacle"` → steer right of pillar.  
  - `"corner_avoid"` → perform sharp predefined turn.  
  - `"line_centering"` → maintain lane using LiDAR + ROI fallback.  

+ **Actuation**  
  - Steering angle sent to **MG996R high-torque servo**.  
  - Motor commands executed via **TB6612FNG motor driver**.  
  - Smooth velocity profiles prevent skidding or abrupt turns.  

+ **System Reliability**  
  - Fusion of LiDAR (geometric accuracy) and Camera (semantic recognition) ensures **redundancy and robustness**.  
  - Fail-safes prevent deadlock when either sensor produces invalid data.  

## Step by step breakdown of functions (obstacle round):

### analyze_black_between_lines(frame, inner_start, inner_end):
```bash
def analyze_black_between_lines(frame, inner_start, inner_end):
    """
    Detects the amount of black pixels between two bounding lines (inner ROI).
    Balances left vs. right black regions to decide correction angle.
    """

    # Convert to grayscale
    gray = cv2.cvtColor(frame, cv2.COLOR_BGR2GRAY)
    x1, y1 = inner_start
    x2, y2 = inner_end

    # Extract Region of Interest (ROI)
    roi = gray[y1:y2, x1:x2]

    # Threshold black areas
    _, black_mask = cv2.threshold(roi, 60, 255, cv2.THRESH_BINARY_INV)

    # Split into left and right halves
    h, w = black_mask.shape
    left = black_mask[:, :w // 2]
    right = black_mask[:, w // 2:]

    # Count black pixels
    black_left = np.sum(left) / 255
    black_right = np.sum(right) / 255
    total_black = black_left + black_right

    # No black detected
    if total_black == 0:
        return None

    # Balance measure: positive → more black on right, negative → more on left
    balance = (black_right - black_left) / total_black

    # Apply gain factor
    correction = KP_LINE_CENTERING * balance * 100
    return correction
```

### Explanation:
+ Converts frame → grayscale and extracts a ROI between two guiding lines.
+ Thresholds dark areas (black tape or shadows).
+ Splits into left and right halves:
  + If more black is on the left → robot drifts left → correction steers right.
  + If more black is on the right → correction steers left.
+ Provides a PID-like correction signal to keep robot centered when no obstacles are detected.

### process_frame_for_steering(frame, use_outer_roi_and_bottom_point=False):
```bash
def process_frame_for_steering(frame, use_outer_roi_and_bottom_point=False):
    """
    Main vision pipeline:
    - Detects red/green obstacles in ROI
    - Applies depth-aware steering adjustment
    - Falls back to black line detection if no obstacle
    - Returns processed frame (for debugging), steering_angle, mask, label
    """

    # Handle empty input
    if frame is None or frame.size == 0:
        return frame, 0, None, "none"

    # Convert to HSV for color segmentation
    hsv = cv2.cvtColor(frame, cv2.COLOR_BGR2HSV)

    # Define HSV ranges for green and red obstacles
    green_mask = cv2.inRange(hsv, GREEN_LOWER, GREEN_UPPER)
    red_mask1 = cv2.inRange(hsv, RED_LOWER1, RED_UPPER1)
    red_mask2 = cv2.inRange(hsv, RED_LOWER2, RED_UPPER2)
    red_mask = cv2.bitwise_or(red_mask1, red_mask2)

    # ROI selection
    if use_outer_roi_and_bottom_point:
        roi = frame[OUTER_ROI_Y1:OUTER_ROI_Y2, OUTER_ROI_X1:OUTER_ROI_X2]
        roi_red = red_mask[OUTER_ROI_Y1:OUTER_ROI_Y2, OUTER_ROI_X1:OUTER_ROI_X2]
        roi_green = green_mask[OUTER_ROI_Y1:OUTER_ROI_Y2, OUTER_ROI_X1:OUTER_ROI_X2]
    else:
        roi = frame[INNER_ROI_Y1:INNER_ROI_Y2, INNER_ROI_X1:INNER_ROI_X2]
        roi_red = red_mask[INNER_ROI_Y1:INNER_ROI_Y2, INNER_ROI_X1:INNER_ROI_X2]
        roi_green = green_mask[INNER_ROI_Y1:INNER_ROI_Y2, INNER_ROI_X1:INNER_ROI_X2]

    # Find contours in red/green masks
    contours_red, _ = cv2.findContours(roi_red, cv2.RETR_EXTERNAL, cv2.CHAIN_APPROX_SIMPLE)
    contours_green, _ = cv2.findContours(roi_green, cv2.RETR_EXTERNAL, cv2.CHAIN_APPROX_SIMPLE)

    steering_angle = 0
    logic_label = "none"

    # Determine largest obstacle contour
    obstacle_contour = None
    color_detected = None
    for c in contours_red:
        if cv2.contourArea(c) > MIN_CONTOUR_AREA:
            obstacle_contour = c
            color_detected = "red"
            break
    for c in contours_green:
        if cv2.contourArea(c) > MIN_CONTOUR_AREA:
            obstacle_contour = c
            color_detected = "green"
            break

    if obstacle_contour is not None:
        # Compute bounding box
        x, y, w, h = cv2.boundingRect(obstacle_contour)
        obstacle_center = x + w // 2
        obstacle_bottom_y = y + h

        # Depth sensitivity: closer objects → stronger corrections
        normalized_depth = 1 - (obstacle_bottom_y / frame.shape[0])
        depth_factor = DEPTH_IMPORTANCE_FACTOR * (1 + normalized_depth)

        # Calculate steering correction
        error = (obstacle_center - (roi.shape[1] // 2))
        steering_angle = KP_STEERING * error * depth_factor

        # Assign logic label
        if color_detected == "red":
            logic_label = "red_obstacle"
        else:
            logic_label = "obstacle"

        # Debug drawing
        cv2.rectangle(roi, (x, y), (x + w, y + h), (0, 255, 255), 2)
        cv2.putText(frame, f"DepthFactor: {depth_factor:.2f}", (10, 30),
                    cv2.FONT_HERSHEY_SIMPLEX, 0.7, (0, 255, 0), 2)
    else:
        # Fallback: use black line detection
        correction = analyze_black_between_lines(frame, (INNER_ROI_X1, INNER_ROI_Y1), (INNER_ROI_X2, INNER_ROI_Y2))
        if correction is not None:
            steering_angle = correction
            logic_label = "line_centering"
        else:
            # Dark corner → assume sharp left turn
            steering_angle = -45
            logic_label = "corner_avoid"

    return frame, steering_angle, (red_mask, green_mask), logic_label
```

### Explanation:
+ Input checks
  + If frame is empty → return defaults.

+ Color filtering
  + HSV thresholds for green obstacles and red obstacles.
  + Masks created → isolate obstacles by color.

+ Region of Interest (ROI) selection
  + Two ROI modes:
    + Inner ROI (default) → normal detection zone.
    + Outer ROI + bottom detection point (when close to obstacles).

+ Contour detection
  + Finds contours in red/green masks.
  + Filters by MIN_CONTOUR_AREA to ignore noise.
  + Chooses the largest obstacle contour.

+ Obstacle classification
  + If red → "red_obstacle" label.
  + If green → "obstacle" label.
  + If none → "none" (fallback logic).

+ Depth-aware steering
  + Uses bottom Y-coordinate of obstacle (obstacle_bottom_y).
  + Normalizes relative to frame height → closer objects give larger values.
  + Multiplies steering correction by DEPTH_IMPORTANCE_FACTOR × normalized_depth.
  + Result: closer obstacles cause sharper steering corrections.

+ Fallback to black line centering
  + If no obstacle detected:
    + Calls analyze_black_between_lines().
    + If even that fails, assumes dark corner → hard left turn (-45°).

+ UI overlays
  + Draws rectangles, centerlines, contours.
  + Displays Depth Factor for debugging.

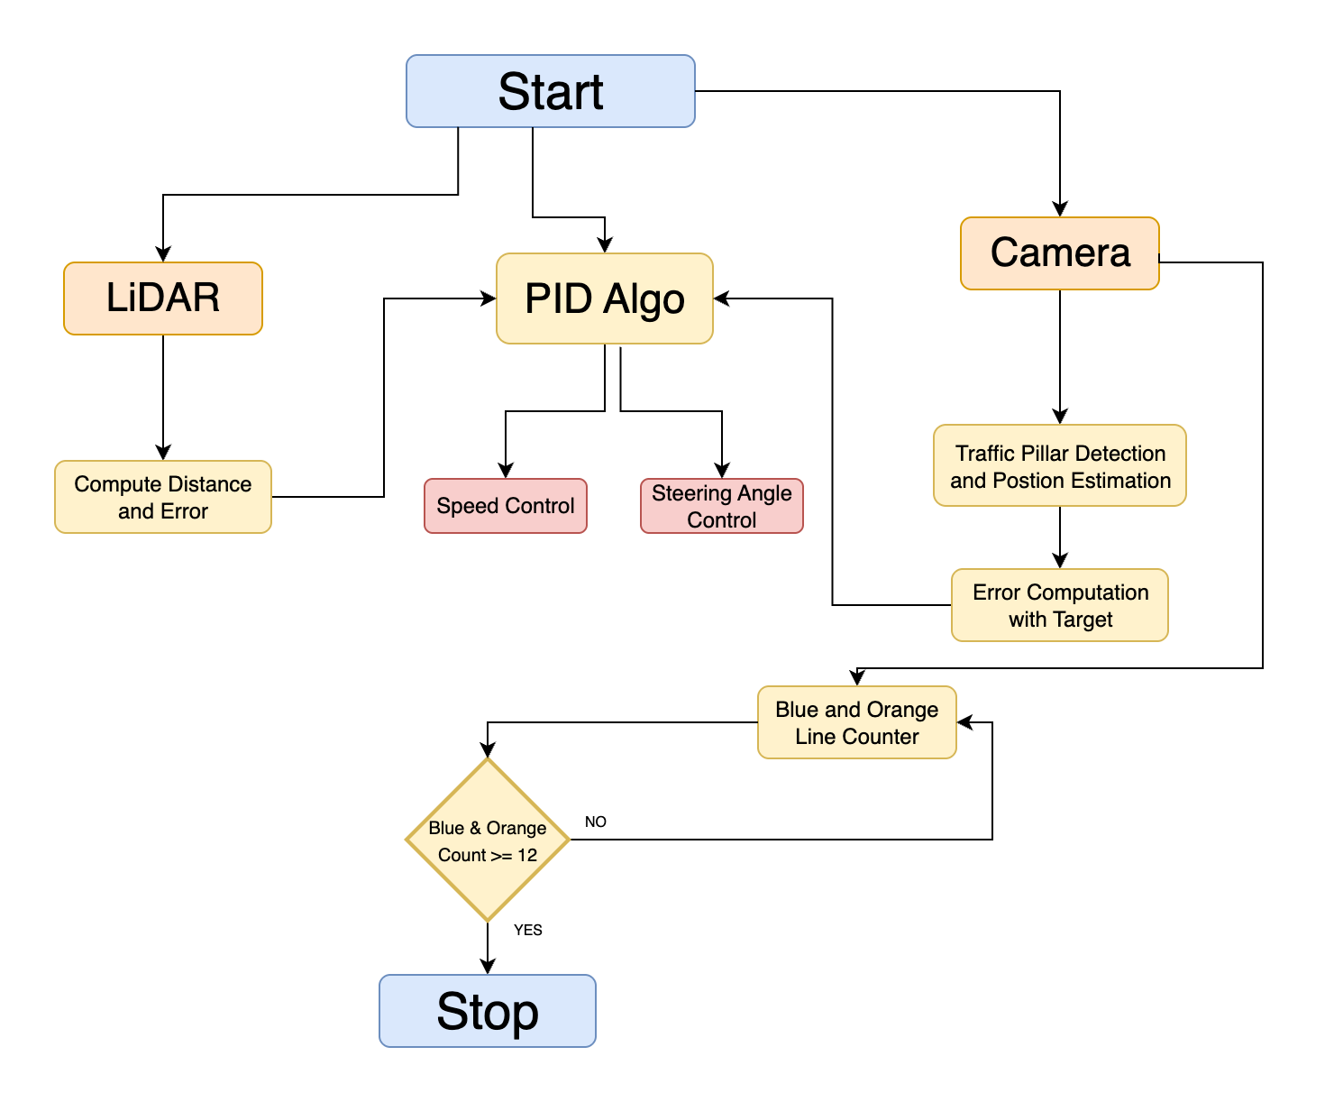
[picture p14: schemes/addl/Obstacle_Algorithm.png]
Obstacle Round Algorithm


### Final Evaluation & Scores
In our testing, we have achieved the following scores:
<table border="1">
  <thead>
    <tr>
      <th>Round</th>
      <th>Max Score Possible</th>
      <th>Score Achieved</th>
      <th>Time (seconds)</th>
    </tr>
  </thead>
  <tbody>
    <tr>
      <td>Open Round</td>
      <td>30</td>
      <td>30</td>
      <td>60</td>
    </tr>
    <tr>
      <td>Obstacle Round</td>
      <td>40</td>
      <td>NA</td>
      <td>150</td>
    </tr>
  </tbody>
</table>

# 🚀 Robot Construction Guide

This document provides a step-by-step guide to building and setting up the robot.  

---

## 🖨️ Step 0: Print the 3D Parts
The 3D printable parts can be found in the `3d-models` folder.  
Recommended printer: **BambuLab X1-Carbon** (or equivalent).  

**Suggested print settings (update once finalized):**
- Material: PLA  
- Layer height: 0.2 mm  
- Infill: 20%  
- Supports: Yes  
- Raft: No  
- Brim: Yes  

---

⚙️ Step 1: Assemble the Chassis & Steering Servo

- Mount the **MG66R servo** onto the chassis using the provided slots or screws/zip ties.  
- Connect the servo horn to the steering linkage slot in the chassis.  
- Ensure the servo wire exits cleanly towards the electronics compartment.  
- The differential system relies on the **N20 motors**, while the servo provides steering correction.  

---

🔩 Step 2: Assemble the Powertrain

- Mount the **motor brackets** onto the chassis using screws.  
- Insert the **N20 gearmotors** into the brackets and secure them tightly.  
- Attach the **N20 wheels** directly to the motor shafts.  
- Ensure both wheels spin freely and remain aligned with the chassis.  
- If spacers are included in the 3D model, use them to level the wheels.  

---

🔌 Step 3: Attach the Electronics

- **Motor Driver (TB6612FNG):**  
  - Mount to the chassis (double-sided tape or 3D mount).  
  - Connect the N20 motors to the A and B outputs.  

- **PWM Controller (PCA9685):**  
  - Fix near the servo.  
  - Connect the MG66R servo to channel 0.  
  - Power the PCA9685 from the main battery (via Pi 5).  

- **Raspberry Pi 5:**  
  - Mount onto the electronics platform.  
  - Connect the TB6612FNG and PCA9685 via GPIO/I²C.  
  - Connect the **LiDAR sensor** via USB or UART (depending on module).  
  - Mount the **PiCamera3 Wide Angle** on the front of the chassis with a slight upward tilt.  

- **Battery Pack:**  
  - Place under or behind the electronics mount.  
  - Secure with Velcro or brackets.  
  - Connect battery output to a 5V regulator if required.  

---

📡 Step 4: Wiring Setup

- **Servo** → PCA9685 (channel 0)  
- **Motors** → TB6612FNG → Raspberry Pi GPIO  
- **PCA9685** → Raspberry Pi (I²C SDA + SCL)  
- **LiDAR** → Raspberry Pi (USB/UART)  
- **PiCamera3** → Raspberry Pi camera slot  

(Optional) Bundle excess wires with zip ties for a clean look.  

---

💻 Step 5: Software Setup

1. Insert a microSD card with **Raspberry Pi OS** into the Pi 5.  
2. Boot and complete first-time setup.  
3. Install dependencies:  
   ```bash
   sudo apt update && sudo apt upgrade -y
   sudo apt install python3-pip i2c-tools
   pip3 install adafruit-circuitpython-servokit rplidar opencv-python
Enable I²C and camera support:
sudo raspi-config

>📥 Step 6: Upload the Code
Open Visual Studio Code on your laptop/desktop.
Connect to the Raspberry Pi via SSH or VS Code Remote.
Upload your control code (motor + servo + LiDAR + camera).
Run the program:
python3 main.py

🛠️ Step 7: Testing & Calibration
Power on the robot.
Test servo movement (ensure center position).
Run a basic motor test to confirm both N20 motors spin correctly.
Adjust LiDAR positioning and camera tilt.
Fine-tune the code for speed, steering, and stability.

📷 Media Placeholders
Add images or diagrams of your build process here:
docs/images/chassis.jpg
docs/images/electronics.jpg
docs/images/wiring.jpg

📝 Raspberry Pi 5 Initialization Steps

### 1. Prepare the microSD Card
- Download the latest **Raspberry Pi OS (64-bit)** from the official Raspberry Pi website.  
- Use **Raspberry Pi Imager** (or BalenaEtcher) to flash the OS to a microSD card (32GB recommended).  
- Insert the flashed microSD card into the Raspberry Pi 5.  

---

### 2. First Boot
- Connect the Pi to a monitor, keyboard, and mouse.  
- Power on the Pi using your battery pack or a 5V/5A USB-C supply.  
- Go through the first-time setup wizard:  
  - Select language, time zone, and keyboard layout.  
  - Connect to Wi-Fi.  
  - Update the system when prompted.  

---

### 3. Enable Required Interfaces
Open terminal and run:
``` bash
  sudo raspi-config

  Enable the following:
  I²C (for PCA9685 servo controller)
  Camera (for PiCamera3)
  SSH (for remote programming from VS Code)
  Serial/UART (if your LiDAR uses UART)
  Reboot the Pi after enabling:
  sudo reboot

  4. Install System Updates & Tools
  Run these commands:
  sudo apt update && sudo apt upgrade -y
  sudo apt install python3-pip git i2c-tools

  5. Install Python Libraries
  Install required libraries for motors, LiDAR, and camera:
  pip3 install adafruit-circuitpython-servokit rplidar opencv-python

  6. (Optional) VS Code Remote Setup
  To program directly from your laptop using Visual Studio Code:
  Install the Remote SSH extension in VS Code.
  Connect to the Pi using its IP address:
  ssh pi@<your_pi_ip>
  Default username: pi
  Default password: raspberry (change this after first login with passwd).
  
``` bash 

## Running the Code
To run the code, follow these steps:

[View LiDAR in 3D](3d/lidar.stl)

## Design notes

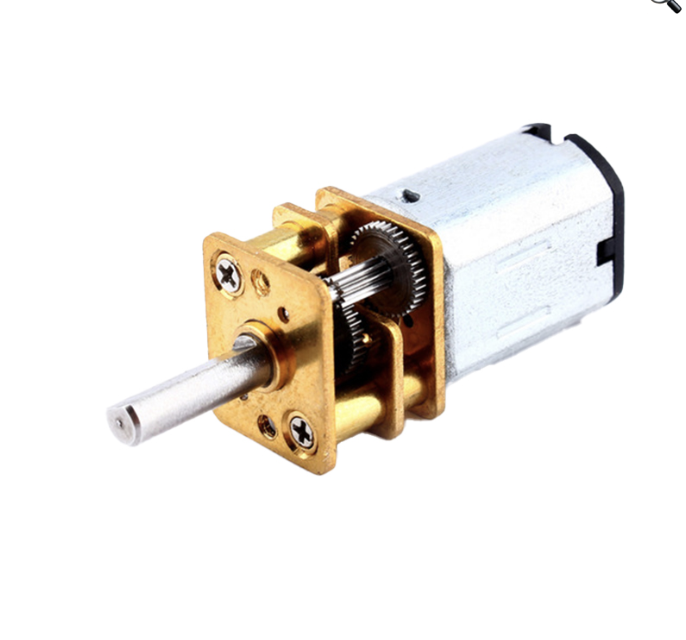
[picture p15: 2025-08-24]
images/n20motor.png

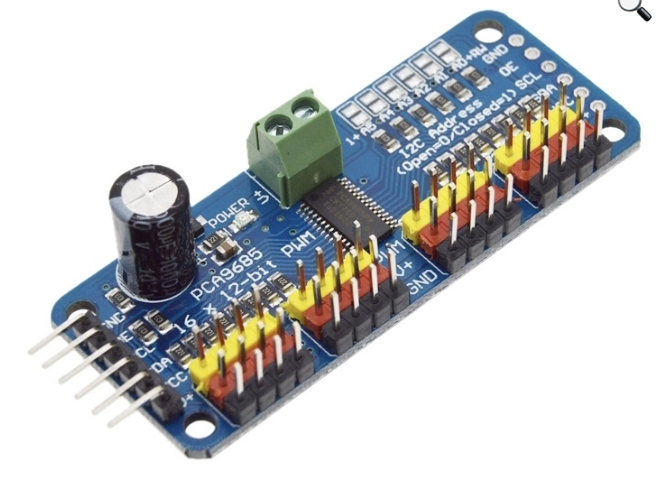
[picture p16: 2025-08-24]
images/PCA9685.png

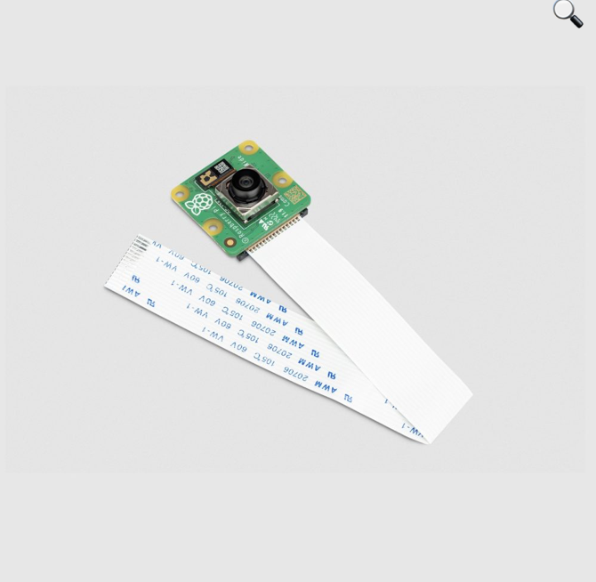
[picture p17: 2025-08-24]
images/picamera3wideangle.png

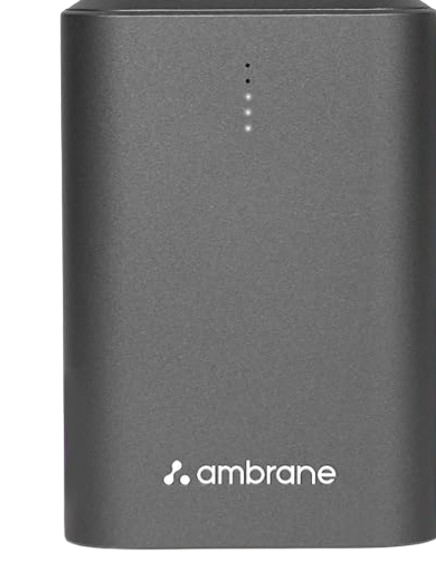
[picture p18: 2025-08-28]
images/Power_Bank.png

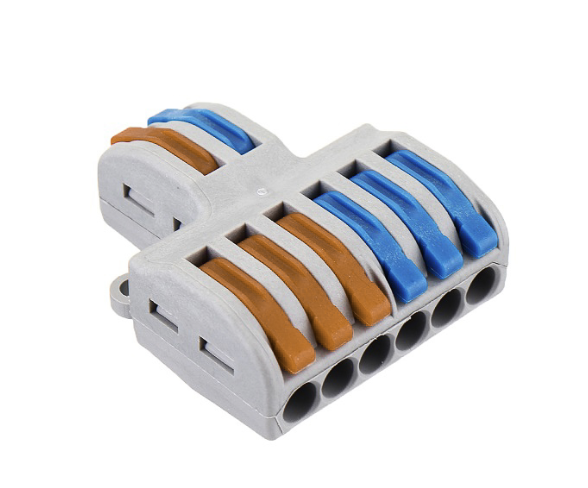
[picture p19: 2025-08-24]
images/wireconnectors.png

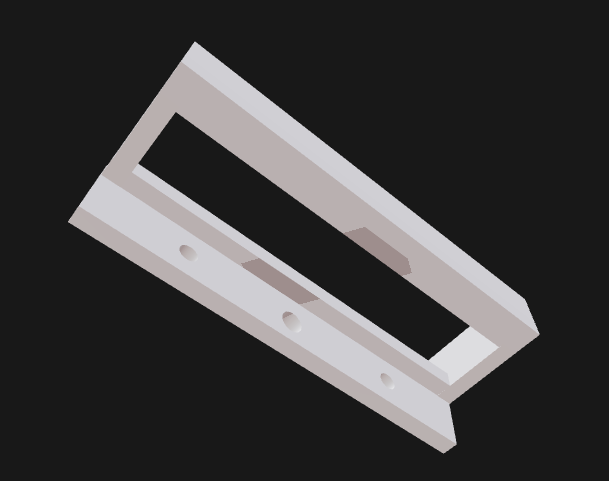
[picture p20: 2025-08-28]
images/BatteryStand_2.png

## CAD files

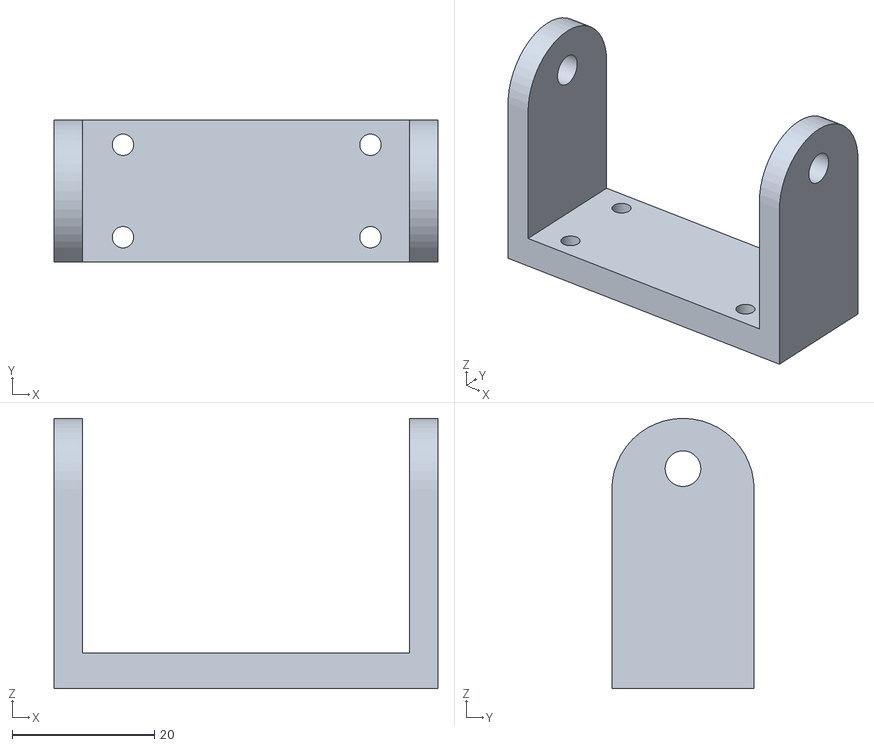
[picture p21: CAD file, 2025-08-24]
3d/Fabulous Lappi (1).stl
54.0 x 20.0 x 38.0

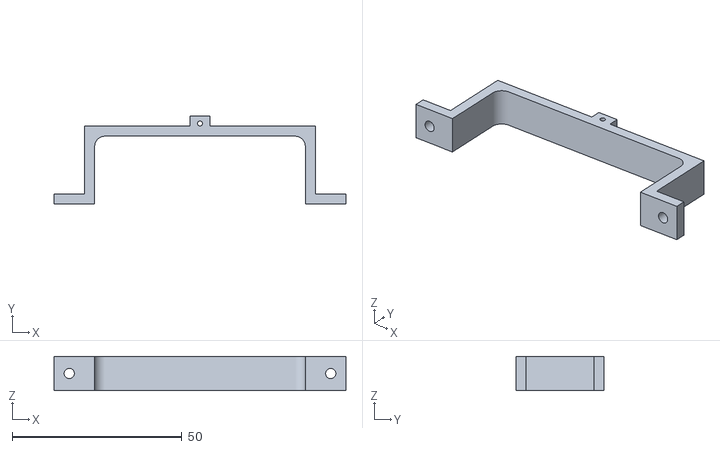
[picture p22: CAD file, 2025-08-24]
3d/Grand Migelo (2).stl
86.0 x 26.0 x 10.0

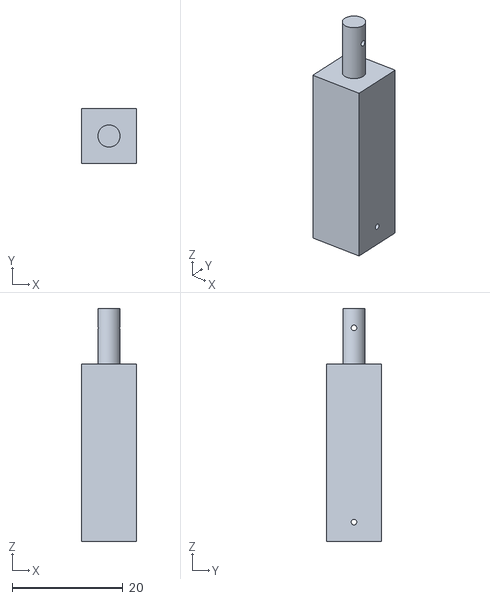
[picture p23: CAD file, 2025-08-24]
3d/layer_support_beam.stl
10.0 x 10.0 x 42.0

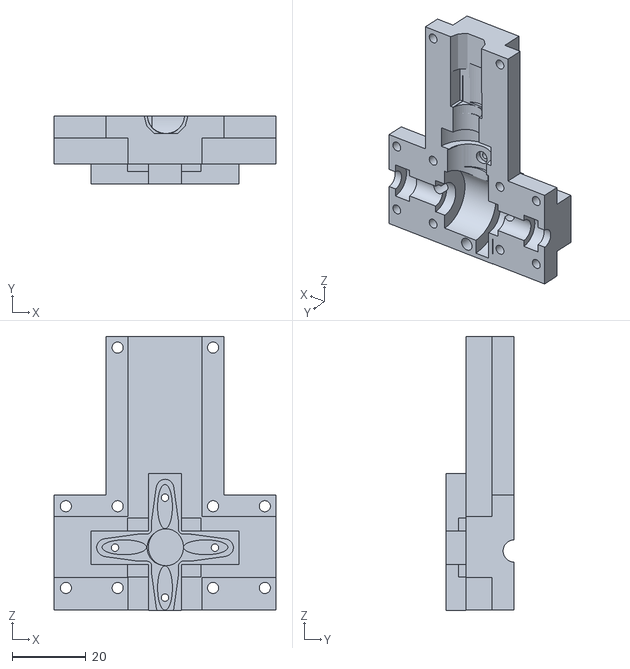
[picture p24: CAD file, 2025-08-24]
3d/differentialgear_stand.stl
60.0 x 18.5 x 74.1

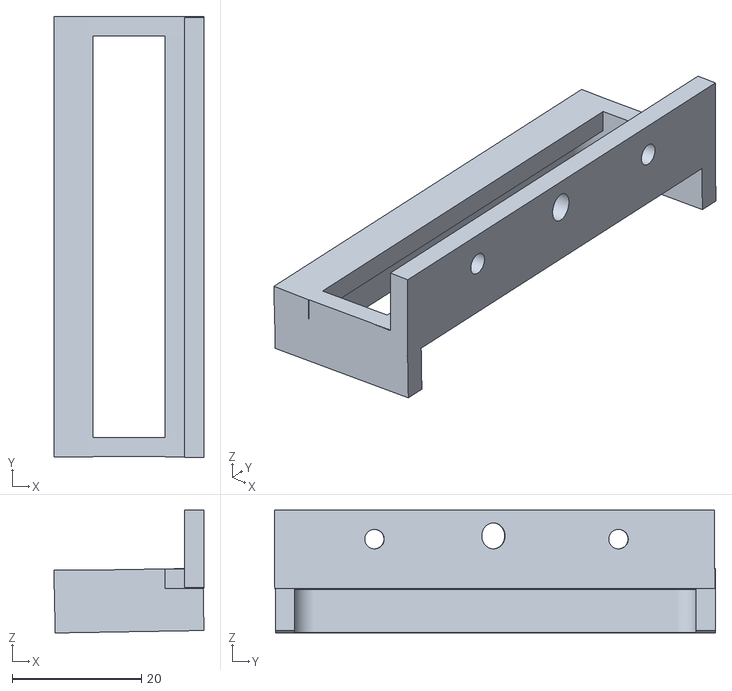
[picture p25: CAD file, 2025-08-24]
3d/batter_stand.stl
23.2 x 68.1 x 19.0

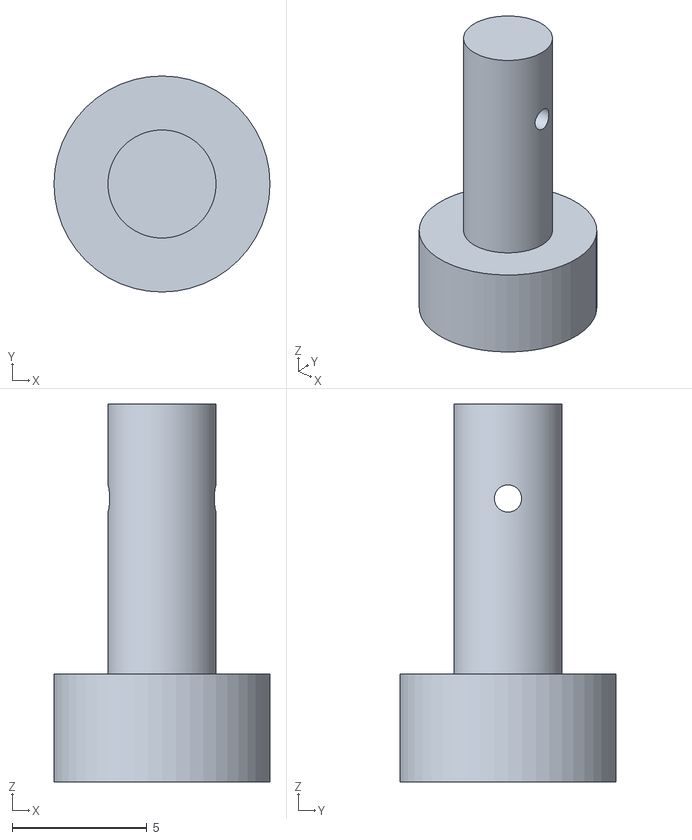
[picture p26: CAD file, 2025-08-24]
3d/rear_axle_holder.stl
8.00 x 8.00 x 14.0

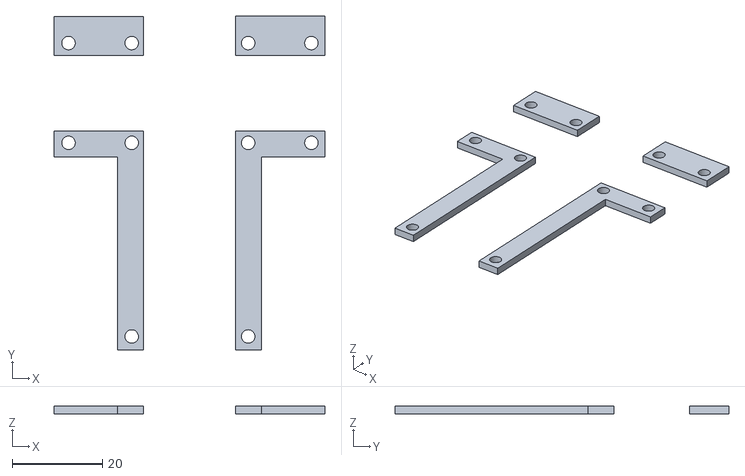
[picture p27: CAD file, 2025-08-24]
3d/differentialgear_3.stl
60.0 x 74.0 x 1.80

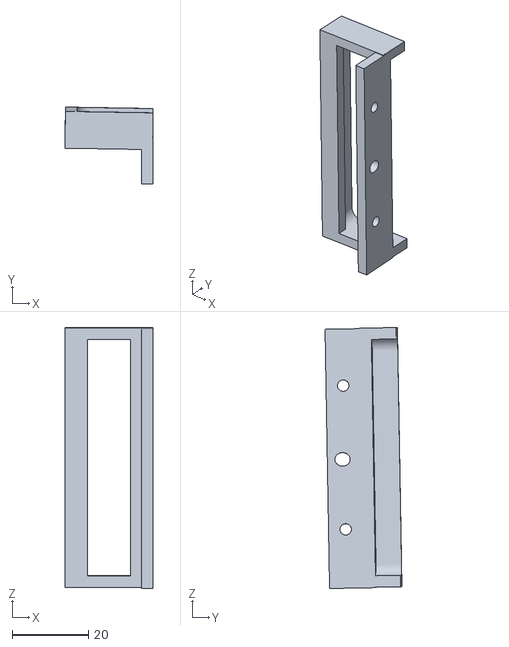
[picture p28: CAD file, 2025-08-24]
3d/battery_holder.stl
23.2 x 20.2 x 68.5

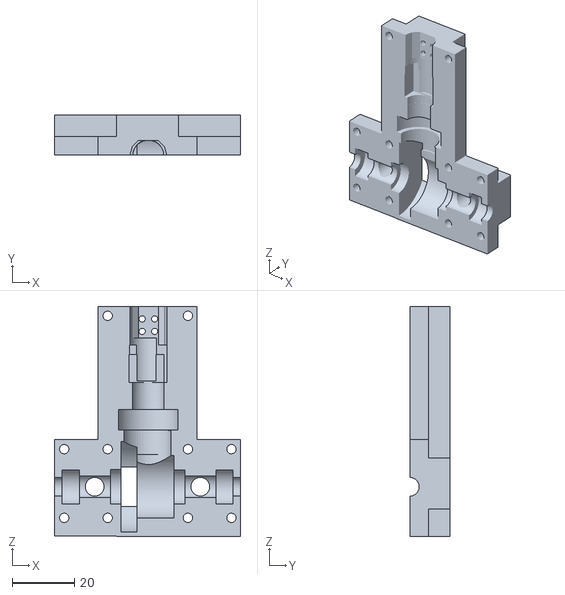
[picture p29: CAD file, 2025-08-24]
3d/differentialgear_2.stl
60.0 x 13.0 x 74.0

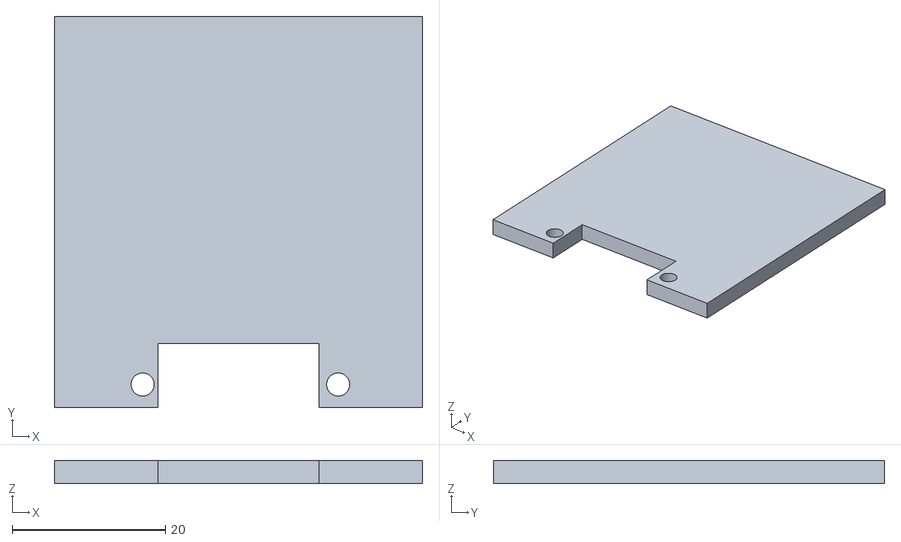
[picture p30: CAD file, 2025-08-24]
3d/lidar.stl
48.0 x 51.0 x 3.00

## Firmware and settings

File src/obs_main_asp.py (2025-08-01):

import cv2
import sys
import numpy as np
from picamera2 import Picamera2
import libcamera
from flask import Flask, render_template, Response
import threading
import time
import os

# Import your custom functions
try:
    from image_frames_asp import analyze_scene
    from robot_motion import adjust_servo_angle, robot_forward_speed, robot_stop, motor_standby
    from lidar_steering2 import LidarScanner, PIDController, calculate_steering_error
except ImportError as e:
    print(f"Error importing modules: {e}")
    sys.exit()

# --- Global Variables ---
output_frame = None
output_frame_lock = threading.Lock()
latest_lidar_data = {}
lidar_data_lock = threading.Lock()

# --- FLASK WEB SERVER SETUP ---
app = Flask(__name__)

# --- ROBOT MISSION CONSTANTS ---
TOTAL_LAPS = 3
CORNERS_PER_LAP = 4
TOTAL_TURNS_TO_COMPLETE = TOTAL_LAPS * CORNERS_PER_LAP

# --- MOTION & STEERING CONSTANTS ---
ROBOT_SPEED = 0.75
STRAIGHT_ANGLE = 90
SHARP_TURN_DEVIATION = 40
SHARP_RIGHT = STRAIGHT_ANGLE - SHARP_TURN_DEVIATION
SHARP_LEFT = STRAIGHT_ANGLE + SHARP_TURN_DEVIATION
SERVO_MIN_ANGLE = 60
SERVO_MAX_ANGLE = 120

# --- VISION-BASED CONTROL GAINS ---
RED_TARGET_X = 110
GREEN_TARGET_X = 660 
VISION_KP = 0.5
VISION_KD = 0.1
VISION_CY = 0.08
WALL_KP = 0.4
WALL_KD = 0.1

# --- LIDAR CONTROL CONSTANTS ---
LIDAR_ENABLED = True
LIDAR_TARGET_DISTANCE_MM = 750
LIDAR_SAFETY_DISTANCE_MM = 300
LIDAR_PID_KP = 0.3
LIDAR_PID_KI = 0.001
LIDAR_PID_KD = 0.02
LIDAR_STEERING_SCALE_FACTOR = 0.2

# --- CAMERA CONFIGURATION ---
CAMERA_RESOLUTION = (768, 432) # (width, height)
CAMERA_FRAMERATE = 30.0
DEBUG_UI_OVERLAYS = True


# --- REGIONS OF INTEREST (ROIs) ---
FRAME_W, FRAME_H = CAMERA_RESOLUTION
ROIS = {
    'wall_left': (0, int(FRAME_H * 0.45), FRAME_W // 2, int(FRAME_H * 0.8)),
    'wall_right': (FRAME_W // 2, int(FRAME_H * 0.45), FRAME_W, int(FRAME_H * 0.8)),
    'pillar': (int(FRAME_W * 0.1), int(FRAME_H * 0.25), int(FRAME_W * 0.9), int(FRAME_H * 0.9)),
    'line': (int(FRAME_W * 0.25), int(FRAME_H * 0.6), int(FRAME_W * 0.75), FRAME_H)
}


# Helper function to map PID output to servo angle for LiDAR
def map_lidar_steering_angle(center_angle, pid_output):
    adjusted_output = pid_output * LIDAR_STEERING_SCALE_FACTOR
    angle = center_angle - adjusted_output
    return max(SERVO_MIN_ANGLE, min(angle, SERVO_MAX_ANGLE))

# LiDAR Data Acquisition Thread Function
def lidar_acquisition_thread_func(scanner_instance):
    global latest_lidar_data, lidar_data_lock
    print("LiDAR acquisition thread started.")
    try:
        while True:
            data = scanner_instance.get_scan_data()
            if data:
                with lidar_data_lock:
                    latest_lidar_data = data
            time.sleep(0.01)
    except Exception as e:
        print(f"LiDAR Acquisition Thread Error: {e}")
    finally:
        print("LiDAR acquisition thread stopping.")
        if scanner_instance:
            scanner_instance.disconnect()

def robot_control_loop():
    global output_frame, output_frame_lock

    # Initialization
    picam2 = Picamera2()
    camera_config = picam2.create_preview_configuration(main={"size": CAMERA_RESOLUTION}, transform=libcamera.Transform(vflip=True, hflip=True), controls={"FrameRate": CAMERA_FRAMERATE})
    picam2.configure(camera_config)
    picam2.start()
    print(f"Camera started with resolution {CAMERA_RESOLUTION}.")

    lidar_scanner, lidar_pid, lidar_acquisition_thread = None, None, None
    if LIDAR_ENABLED:
        try:
            lidar_scanner = LidarScanner()
            lidar_scanner.connect()
            lidar_acquisition_thread = threading.Thread(target=lidar_acquisition_thread_func, args=(lidar_scanner,))
            lidar_acquisition_thread.daemon = True
            lidar_acquisition_thread.start()
            lidar_pid = PIDController(Kp=LIDAR_PID_KP, Ki=LIDAR_PID_KI, Kd=LIDAR_PID_KD, setpoint=0)
            print("LiDAR system initialized successfully.")
        except IOError as e:
            print(f"WARNING: Failed to initialize LiDAR: {e}. Running in vision-only mode.")
            lidar_scanner = None

    # Mission State Variables
    t = 0
    turnDir = "none"
    lTurn, rTurn = False, False

    # PD Controller State Variables
    vision_prev_error = 0.0
    wall_prev_diff = 0.0
    
    current_mode = "Initializing"

    try:
        while True:
            frame_bgr = cv2.cvtColor(picam2.capture_array(), cv2.COLOR_RGB2BGR)
            
            processed_frame, scene_data = analyze_scene(frame_bgr, ROIS)

            if not scene_data:
                time.sleep(0.01)
                continue

            # Mission Completion Check
            if t >= TOTAL_TURNS_TO_COMPLETE:
                if current_mode != "STOPPED":
                    print(f"Mission Complete! {TOTAL_LAPS} Laps finished. Stopping.")
                    robot_stop()
                    current_mode = "STOPPED"
                
                if DEBUG_UI_OVERLAYS:
                    cv2.putText(processed_frame, "MISSION COMPLETE", (120, 220), cv2.FONT_HERSHEY_TRIPLEX, 2, (0, 255, 0), 4)
                with output_frame_lock:
                    output_frame = processed_frame.copy()
                time.sleep(0.1)
                continue
            
            pillar = scene_data["closest_pillar"]
            angle = STRAIGHT_ANGLE

            # --- BEHAVIOR ARBITRATION LOGIC ---
            if lTurn or rTurn:
                current_mode = f"Cornering {'Left' if lTurn else 'Right'}"
                exit_thresh = 4000
                if (rTurn and scene_data["left_wall_area"] >= exit_thresh) or \
                   (lTurn and scene_data["right_wall_area"] >= exit_thresh):
                    lTurn, rTurn = False, False
                    t += 1
                    print(f"--- Turn {t} Complete ---")
                else:
                    angle = SHARP_LEFT if lTurn else SHARP_RIGHT
            elif pillar.color is not None:
                if pillar.color == 'red':
                    target_x = RED_TARGET_X
                    current_mode = "Pillar: Red -> Steer RIGHT"
                else: 
                    target_x = GREEN_TARGET_X
                    current_mode = "Pillar: Green -> Steer LEFT"

                vision_error = target_x - pillar.x
                angle = STRAIGHT_ANGLE + (vision_error * VISION_KP) + ((vision_error - vision_prev_error) * VISION_KD)
                ROI_TOP_Y = ROIS['pillar'][1]
                y_correction = VISION_CY * (pillar.y - ROI_TOP_Y)
                angle += -y_correction if vision_error <= 0 else y_correction
                vision_prev_error = vision_error
                wall_prev_diff = 0
            else:
                vision_prev_error = 0.0
                if turnDir == "none":
                    if scene_data["orange_line_area"] > 100: turnDir = "right"
                    elif scene_data["blue_line_area"] > 100: turnDir = "left"
                
                if (turnDir == "right" and scene_data["orange_line_area"] > 100) or \
                   (turnDir == "left" and scene_data["blue_line_area"] > 100):
                    lTurn = (turnDir == "left")
                    rTurn = (turnDir == "right")
                    angle = SHARP_LEFT if lTurn else SHARP_RIGHT
                elif lidar_scanner:
                    current_mode = "LiDAR Wall Follow"
                    with lidar_data_lock: scan_data = latest_lidar_data.copy()
                    if scan_data:
                        lidar_error = calculate_steering_error(scan_data, LIDAR_TARGET_DISTANCE_MM, LIDAR_SAFETY_DISTANCE_MM)
                        if lidar_error == 9999.0:
                             robot_stop()
                             current_mode = "STOP (LiDAR Obstacle)"
                             time.sleep(0.1)
                             continue
                        else:
                            pid_output = lidar_pid.update(lidar_error)
                            angle = map_lidar_steering_angle(STRAIGHT_ANGLE, pid_output)
                else:
                    current_mode = "Lane Keeping (Vision)"
                    wall_diff = scene_data["right_wall_area"] - scene_data["left_wall_area"]
                    angle = STRAIGHT_ANGLE + (wall_diff * WALL_KP) + ((wall_diff - wall_prev_diff) * WALL_KD)
                    wall_prev_diff = wall_diff

            # --- Final Actuation ---
            final_angle = np.clip(angle, SERVO_MIN_ANGLE, SERVO_MAX_ANGLE)
            adjust_servo_angle(final_angle)
            robot_forward_speed(ROBOT_SPEED)

            # Update UI Overlays
            if DEBUG_UI_OVERLAYS:
                cv2.putText(processed_frame, f"Mode: {current_mode}", (20, 40), cv2.FONT_HERSHEY_SIMPLEX, 0.7, (255, 255, 0), 2)
                cv2.putText(processed_frame, f"Turns: {t}/{TOTAL_TURNS_TO_COMPLETE}", (20, 70), cv2.FONT_HERSHEY_SIMPLEX, 0.7, (0, 255, 255), 2)
                cv2.putText(processed_frame, f"Angle: {int(final_angle)}", (processed_frame.shape[1] - 150, 40), cv2.FONT_HERSHEY_SIMPLEX, 0.8, (0, 255, 0), 2)

            with output_frame_lock:
                output_frame = processed_frame.copy()

    finally:
        print("Control loop ending...")
        robot_stop()
        picam2.stop()
        print("Robot and camera resources released.")

# --- Flask Streaming Functions and Main Execution Block ---
def generate_frames():
    global output_frame, output_frame_lock
    while True:
        with output_frame_lock:
            if output_frame is None:
                time.sleep(0.01)
                continue
            (flag, encoded_image) = cv2.imencode(".jpg", output_frame)
            if not flag:
                continue
        yield (b'--frame\r\n' b'Content-Type: image/jpeg\r\n\r\n' + bytearray(encoded_image) + b'\r\n')

@app.route("/")
def index():
    return render_template("index.html")

@app.route("/video_feed")
def video_feed():
    return Response(generate_frames(), mimetype="multipart/x-mixed-replace; boundary=frame")

if __name__ == '__main__':
    print("--- Starting Robot Control System ---")
    robot_stop()
    motor_standby()
    time.sleep(0.5)

    control_thread = threading.Thread(target=robot_control_loop)
    control_thread.daemon = True
    control_thread.start()
    print("Robot control thread started.")

    hostname = os.uname()[1]
    print(f"Web server starting. Open http://{hostname}.local:5000 or http://<raspberrypi_ip>:5000")
    app.run(host='0.0.0.0', port=5000, debug=False, threaded=True, use_reloader=False)

    print("Main application exiting.")

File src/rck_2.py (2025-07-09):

import time
import os # For creating directories
import threading # For running camera capture in a separate thread
import sys # For clean exit
import keyboard

from gpiozero import DigitalOutputDevice, PWMOutputDevice
from time import sleep # Already imported, keeping for clarity if used elsewhere

# Camera imports
from picamera2 import Picamera2
import libcamera
# Standard imports for Picamera2
# import libcamera.controls # Useful for advanced camera controls if needed

import board
from adafruit_servokit import ServoKit
from adafruit_extended_bus import ExtendedI2C as I2C_Extended

# --- Motor Control Setup ---
# Define GPIO pins (BCM numbering)
# For Motor A
AIN1 = DigitalOutputDevice(24)  # Connected to TB6612FNG AIN1
AIN2 = DigitalOutputDevice(23)  # Connected to TB6612FNG AIN2
PWMA_ENABLE = PWMOutputDevice(12)  # Changed to PWMOutputDevice for speed control
STBY = DigitalOutputDevice(25)  # Connected to TB6612FNG STBY

MOTOR_SPEED = 1.0  # Default motor speed (can be adjusted)

def motor_forward(speed=MOTOR_SPEED):
    """
    Drives the motor forward at given speed (0.0 to 1.0).
    """
    STBY.on()
    AIN1.on()
    AIN2.off()
    PWMA_ENABLE.value = speed

def motor_backward(speed=MOTOR_SPEED):
    """
    Drives the motor backward at given speed (0.0 to 1.0).
    """
    STBY.on()
    AIN1.off()
    AIN2.on()
    PWMA_ENABLE.value = speed

def motor_stop():
    """
    Stops the motor (coasting).
    """
    STBY.on()
    AIN1.off()
    AIN2.off()
    PWMA_ENABLE.value = 0

def motor_brake():
    """
    Brakes the motor (short brake).
    PWMA must be high for brake to be effective.
    """
    STBY.on()
    AIN1.on()
    AIN2.on()
    PWMA_ENABLE.value = 1

def motor_standby():
    """
    Puts the motor driver in standby mode to save power.
    """
    PWMA_ENABLE.value = 0
    STBY.off()

def robot_forward():
    print("Robot: Moving Forward")
    motor_forward(MOTOR_SPEED)

def robot_backward():
    print("Robot: Moving Backward")
    motor_backward(MOTOR_SPEED)

def robot_stop():
    print("Robot: Stopping")
    motor_stop()


# --- Servo Control Setup ---
i2c_bus = I2C_Extended(4) # Use the bus ID (e.g., 4) that you set in config.txt
kit = ServoKit(channels=16, i2c=i2c_bus)

SERVO_INDEX = 0
SERVO_MIN_ANGLE = 0
SERVO_MAX_ANGLE = 180
SERVO_INCREMENT = 5 # Degrees to move per key press

# Set initial servo position and pulse width range
kit.servo[SERVO_INDEX].set_pulse_width_range(500, 2500)
current_servo_angle = 75 # Initial angle
kit.servo[SERVO_INDEX].angle = current_servo_angle
print(f"Servo {SERVO_INDEX} initialized to {current_servo_angle} degrees.")

def adjust_servo_angle(direction):
    global current_servo_angle
    new_angle = current_servo_angle

    if direction == "increase":
        new_angle = min(SERVO_MAX_ANGLE, current_servo_angle + SERVO_INCREMENT)
    elif direction == "decrease":
        new_angle = max(SERVO_MIN_ANGLE, current_servo_angle - SERVO_INCREMENT)
    else:
        return

    if new_angle != current_servo_angle:
        current_servo_angle = new_angle
        kit.servo[SERVO_INDEX].angle = current_servo_angle
        print(f"Servo {SERVO_INDEX} moved to {current_servo_angle} degrees.")

# --- Camera Setup ---
picam2 = None # Global variable to hold the Picamera2 object
camera_running_flag = False # Global flag to control the camera thread's loop

def camera_capture_thread():
    """
    This function runs in a separate thread to capture images periodically.
    """
    global picam2
    global camera_running_flag

    try:
        # Create a directory for images if it doesn't exist
        image_dir = "captured_images"
        os.makedirs(image_dir, exist_ok=True)
        print(f"Camera: Images will be saved to: {os.path.abspath(image_dir)}")

        picam2 = Picamera2()
        # Configure camera for a reasonable resolution for quick capture
        # main={"size": (1280, 720)} is a common choice. Adjust as needed.
        # Adding 'format' to explicitly set JPEG if desired, though .capture_file() implies it
        camera_config = picam2.create_preview_configuration(main={"size": (1640, 1232)},
                                                            transform=libcamera.Transform(vflip=True, hflip=True)) # <--- THIS IS THE CHANGE
        picam2.configure(camera_config)
        
        picam2.start()
        print("Camera: Started. Warming up...")
        # Give camera a moment to warm up and settle
        time.sleep(2) 
        print("Camera: Ready for capture.")

        camera_running_flag = True
        while camera_running_flag:
            timestamp = time.strftime("%Y%m%d_%H%M%S")
            filename = os.path.join(image_dir, f"image_{timestamp}.jpg")
            
            # Capture a full resolution image (if using main stream)
            # You might need to specify a different stream for capture_file if configured
            # For simpler use, create_still_configuration() is often used for photos
            # but for periodic capture, the preview stream can work.
            picam2.capture_file(filename) 
            print(f"Camera: Captured: {filename}")
            time.sleep(0.5) # Capture every half second

    except Exception as e:
        print(f"Camera Error in capture thread: {e}")
    finally:
        if picam2:
            if picam2.started: # Check if camera was successfully started before stopping
                print("Camera: Stopping...")
                picam2.stop()
            picam2.close()
            print("Camera: Stopped and closed.")


# --- Keyboard Control ---
# Keep track of pressed keys for motor control to avoid stopping immediately
# and to manage "on_release" behavior
pressed_motor_keys = set()
exit_flag = False # Flag to signal main loop to exit
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

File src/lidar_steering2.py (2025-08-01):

import serial
import struct
import math
import time
import ydlidar

# --- LiDAR Scanner Class ---
class LidarScanner:
    def __init__(self, port='/dev/ttyUSB0', baudrate=230400):
        self.port = port
        self.baudrate = baudrate
        self.laser = None
        self.scan_data = {}

        self.MIN_ANGLE = -180.0
        self.MAX_ANGLE = 180.0
        self.MIN_RANGE = 0.02
        self.MAX_RANGE = 16.0

    def __enter__(self):
        self.connect()
        return self

    def __exit__(self, exc_type, exc_val, exc_tb):
        self.disconnect()

    def connect(self):
        try:
            ydlidar.os_init()
            self.laser = ydlidar.CYdLidar()

            self.laser.setlidaropt(ydlidar.LidarPropSerialPort, self.port)
            self.laser.setlidaropt(ydlidar.LidarPropSerialBaudrate, self.baudrate)
            self.laser.setlidaropt(ydlidar.LidarPropLidarType, ydlidar.TYPE_TRIANGLE)
            self.laser.setlidaropt(ydlidar.LidarPropScanFrequency, 10.0)
            self.laser.setlidaropt(ydlidar.LidarPropSampleRate, 4)
            self.laser.setlidaropt(ydlidar.LidarPropSingleChannel, False)
            self.laser.setlidaropt(ydlidar.LidarPropMaxAngle, self.MAX_ANGLE)
            self.laser.setlidaropt(ydlidar.LidarPropMinAngle, self.MIN_ANGLE)
            self.laser.setlidaropt(ydlidar.LidarPropMaxRange, self.MAX_RANGE)
            self.laser.setlidaropt(ydlidar.LidarPropMinRange, self.MIN_RANGE)
            self.laser.setlidaropt(ydlidar.LidarPropIntenstiy, True)

            ret = self.laser.initialize()
            if not ret:
                raise IOError(f"LiDAR connection failed: {self.laser.DescribeError()}")

            ret = self.laser.turnOn()
            if not ret:
                raise IOError(f"Failed to turn on YDLIDAR: {self.laser.DescribeError()}")

            print(f"LiDAR: Connected to {self.port} at {self.baudrate} baud.")
        except Exception as e:
            print(f"LiDAR ERROR: Could not connect to LiDAR: {e}")
            raise IOError(f"LiDAR connection failed: {e}")

    def disconnect(self):
        if self.laser:
            print("LiDAR: Disconnecting...")
            self.laser.turnOff()
            self.laser.disconnecting()
            self.laser = None
            print("LiDAR: Disconnected.")

    def get_scan_data(self):
        if not self.laser:
            return None

        self.scan_data = {}
        scan = ydlidar.LaserScan()

        try:
            r = self.laser.doProcessSimple(scan)
            if r:
                for p in scan.points:
                    if self.MIN_RANGE <= p.range <= self.MAX_RANGE:
                        angle_degrees = round(math.degrees(p.angle))
                        distance_mm = p.range * 1000
                        self.scan_data[angle_degrees] = distance_mm
                return self.scan_data
            else:
                return None
        except Exception as e:
            print(f"LiDAR DATA ERROR: {e}")
            return None


# --- PID Controller Class (No changes needed) ---
class PIDController:
    def __init__(self, Kp, Ki, Kd, setpoint=0):
        self.Kp = Kp
        self.Ki = Ki
        self.Kd = Kd
        self.setpoint = setpoint
        self.prev_error = 0
        self.integral = 0
        self.last_time = time.time()

    def update(self, current_error):
        current_time = time.time()
        dt = current_time - self.last_time

        if dt <= 0:
            return self.prev_error

        P = self.Kp * current_error
        self.integral += current_error * dt
        I = self.Ki * self.integral
        derivative = (current_error - self.prev_error) / dt
        D = self.Kd * derivative
        output = P + I + D
        self.prev_error = current_error
        self.last_time = current_time
        return output

    def reset(self):
        self.prev_error = 0
        self.integral = 0
        self.last_time = time.time()


# --- Steering Error Calculation (Angle Ranges Review) ---
def calculate_steering_error(scan_data, target_distance_mm=750, safety_distance_mm=300):
    """
    Calculates the steering error based on LiDAR scan data to keep the robot
    at a target distance from the walls.

    Args:
        scan_data (dict): Dictionary of angle:distance_mm from LiDAR (angles in degrees).
        target_distance_mm (int): The desired distance from the wall in millimeters.
        safety_distance_mm (int): If any point is closer than this, consider it an immediate obstacle.

    Returns:
        float: The steering error. Positive implies turn right, negative implies turn left.
               Returns a large error if an immediate obstacle is detected.
    """

    # Define angular ranges for left, right, and front detection
    # Assuming 0 degrees is directly forward with YDLIDAR T-mini Plus.
    # Angles typically increase counter-clockwise (-180 to 180 degrees).

    # Front sector (for obstacle detection / general clearance)
    # This range is good for typical forward obstacles.
    front_angles_degrees = [angle for angle in range(-15, 16)] # From -15 to +15 degrees

    # Right wall sensing sector
    # If 0 is robot front, 90 is directly right. So, range like 30 to 90 or 45 to 90.
    # The current range (30 to 91) looks reasonable if you want to pick up points directly to the side and slightly forward.
    right_wall_angles_degrees = [angle for angle in range(30, 91)]

    # Left wall sensing sector
    # If 0 is robot front, -90 is directly left. So, range like -90 to -30 or -90 to -45.
    # The current range (-90 to -29) looks reasonable.
    left_wall_angles_degrees = [angle for angle in range(-90, -29)]


    # --- Immediate Obstacle Detection (Safety) ---
    for angle in front_angles_degrees:
        if angle in scan_data and scan_data[angle] is not None and scan_data[angle] < safety_distance_mm and scan_data[angle] > 0:
            print(f"LiDAR: WARNING! Obstacle detected at {angle} deg, {scan_data[angle]:.0f}mm. Commanding full stop/re-evaluation.")
            return 9999.0 # Large error to trigger immediate action (e.g., stop or emergency turn)

    # --- Wall Following Logic ---
    right_distances = [scan_data[angle] for angle in right_wall_angles_degrees if angle in scan_data and scan_data[angle] is not None and scan_data[angle] > 0]
    left_distances = [scan_data[angle] for angle in left_wall_angles_degrees if angle in scan_data and scan_data[angle] is not None and scan_data[angle] > 0]

    avg_right_distance = sum(right_distances) / len(right_distances) if right_distances else None
    avg_left_distance = sum(left_distances) / len(left_distances) if left_distances else None

    error = 0.0
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

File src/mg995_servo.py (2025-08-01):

import board
from adafruit_servokit import ServoKit
import time

from adafruit_extended_bus import ExtendedI2C as I2C_Extended

i2c_bus = I2C_Extended(4) # Use the bus ID (e.g., 4) that you set in config.txt
kit = ServoKit(channels=16, i2c=i2c_bus)

kit.servo[1].set_pulse_width_range(500, 2500)
# kit.servo[1].angle = 90
# time.sleep(0.25)
# kit.servo[1].angle = 70
# time.sleep(0.25)
kit.servo[1].angle = 90
time.sleep(0.25)
# kit.servo[1].angle = 110
# time.sleep(0.25)
# kit.servo[1].angle = 90
# time.sleep(0.25)



# time.sleep(5)

for angle in range(90, 65, -3):
    kit.servo[1].angle = angle
    print(f"Servo Angle : {angle}")
    time.sleep(0.5)

# kit.servo[1].angle = 90
# for angle in range(100, 70, -3):
#     kit.servo[0].angle = angle
#     print(f"Servo Angle : {angle}")
#     time.sleep(1)

# kit.servo[0].angle = 75

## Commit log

2025-07-09 JULY92025
    Added codes for processed frames, robot motion, main.py
2025-08-01 1AUGUST2025 - UPDATED REPOSITORY
    Updated repository with new codes for open round challenge, sensors and robot motion.
2025-08-17 added images to steering and drive
2025-08-17 added flowcharts for open and obstacle rounds
2025-08-24 AUGUST242025
    3D models added
    [Fabulous Lappi (1).stl, Grand Migelo (2).stl, batter_stand.stl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]
